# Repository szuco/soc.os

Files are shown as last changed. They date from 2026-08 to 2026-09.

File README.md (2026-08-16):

# KiCad SwitchStack

Dreistufiges ESP32-Steuerungsmodul für eine massive Schalter-Unterputzdose (61 mm tief).
Drei gestapelte Leiterplatten steuern zwei 24-V-Jalousiemotoren, lesen Sensorik aus und
kommunizieren primär über RS-485. **Bottom und Mid sind rund (Ø 52 mm) und sitzen in der
Dose; Top ist quadratisch (47 × 47 mm) und sitzt davor** — hinter der Busch-Jaeger
Zentralscheibe 6435-914, deren Drucktasten in den Ecken liegen.

## Zentrale Designregel

Das System ist konsequent in drei Stör- und Leistungsdomänen getrennt:

| Ebene | Projekt | Domäne |
|---|---|---|
| **TOP** | `hardware/top_ui` | UI und Sensorik |
| **MID** | `hardware/mid_logic` | Digitale Logik und Kommunikation |
| **BOTTOM** | `hardware/bottom_power_motor`  | 24-V-Leistung, Motoren, DC/DC |

Hochstrom bleibt **vollständig** auf dem Bottom-Board. Die Board-to-Board-Stackverbinder
transportieren ausschließlich Signale und Kleinleistung. Diese Trennung ist für Bauraum,
EMV, Messqualität und Wartbarkeit zentral.

## Eckdaten

- Versorgung: 24 V DC über zwei Adern
- 2 × Klappladenmotor 24 V DC ±10 %, 2 Adern, Umpolung — Laufstrom ≈ 0,3–1,0 A, Blockierstrom offen
- Herrnhuter Mini-Weihnachtsstern 6,0–6,5 V / 0,5 W / ≈ 80 mA, nur im 24-V-Normalbetrieb
- USB-C ausschließlich für Programmierung und Debug
- Positionserkennung ausschließlich über Stromverlauf und Timeout, keine Endschalter
- KiCad-Version: **10.0.5** (migriert von 9.0.7, siehe `docs/08-kicad-workflow.md`)

## Dokumentation

| Dokument | Inhalt |
|---|---|
| [`docs/00-system-overview.md`](docs/00-system-overview.md) | Gesamtsystem, Peripherie, Board-Aufteilung |
| [`docs/01-power-tree.md`](docs/01-power-tree.md) | Power-Tree, Strombilanz, USB-ORing, Schutz |
| [`docs/02-motor-control.md`](docs/02-motor-control.md) | H-Bridges, Strommessung, Überstromschutz, Software-Konzept |
| [`docs/03-stack-pinout.md`](docs/03-stack-pinout.md) | Stackverbinder, verbindliches Pinmapping |
| [`docs/04-mechanical.md`](docs/04-mechanical.md) | Outline, Bohrbild, Koordinaten, Tiefenbudget |
| [`docs/05-manufacturing.md`](docs/05-manufacturing.md) | Lagenaufbau, Kupfer, DRC, Fertigungsdaten |
| [`docs/06-open-decisions.md`](docs/06-open-decisions.md) | Offene Bauteil- und Auslegungsentscheidungen |
| [`docs/07-roadmap.md`](docs/07-roadmap.md) | Konkrete Arbeitsschritte in Reihenfolge |
| [`docs/08-kicad-workflow.md`](docs/08-kicad-workflow.md) | KiCad-Konventionen, Bedienhinweise, Repo-Regeln |
| [`docs/09-display-and-mcu.md`](docs/09-display-and-mcu.md) | Displaywahl, MCU, GPIO-Budget, ESPHome-Grenzen |
| [`docs/10-firmware-strategy.md`](docs/10-firmware-strategy.md) | Firmware-Schichten, ESPHome-Unabhängigkeit, Modbus-Pfad |
| [`docs/11-motor-data.md`](docs/11-motor-data.md) | Motordatenblatt, Leistungsanalyse, **Messprotokoll M1–M7** |
| [`docs/12-legacy-socos.md`](docs/12-legacy-socos.md) | Vorgängerprojekt SoC OS: übernommene Anforderungen, verlorene Funktionen, Restriktionen |
| [`docs/13-funktionsstatus.md`](docs/13-funktionsstatus.md) | **Was steht, was fehlt** — Hardware, Firmware und Mechanik nebeneinander |
| [`hardware/bom/README.md`](hardware/bom/README.md) | Beschaffungsliste, Fertigerempfehlung, Bestellweg |

## Repository-Struktur

```
hardware/
  bottom_power_motor/   KiCad BOTTOM (24 V, Motor, DC/DC)
  mid_logic/            KiCad MID (ESP32-S3, RS-485, Expander, PhotoMOS, Piezo)
  top_ui/               KiCad TOP (USB-C, Display 1,69", 4 Ecktaster, SHT4x, ToF, Stern)
  lib/                  Gemeinsame Symbol-/Footprint-/3D-Bibliotheken
  bom/                  Beschaffung und Fertigerempfehlung
  fab/                  Erzeugte Fertigungsdaten und der Nutzen (Build-Ergebnis)
mechanical/             Adapter zur BJ-Zentralscheibe: build123d-Modell, STEP/STL
tools/                  Generatoren (Mechanik, Schaltpläne, Layouts, Routing, Fertigung)
firmware/
  esphome/              ESPHome-Konfiguration für Home Assistant
docs/                   Projektübergreifende Spezifikationen
```

Ein Verzeichnis `archive/` mit dem Altbestand der Vorgängerprojekte gab es bis zum
15.08.2026. Es ist ausgewertet und entfernt; das Ergebnis steht in
[`docs/12-legacy-socos.md`](docs/12-legacy-socos.md), die Dateien selbst liegen nur
noch in der Git-Historie.

## Erzeugen

Die mechanischen Teile sind **generiert, nicht handgezeichnet** — damit können die drei
Boards nicht auseinanderlaufen:

```bash
python3 tools/gen_boards.py          # 3 × .kicad_pcb: Outline, Bohrbild, Keepout
python3 tools/gen_bottom_sch.py      # Bottom-Schaltplan + BOM, mit Netzlistenprüfung
python3 tools/gen_mid_sch.py         # Mid-Schaltplan (ESP32, RS-485, Expander)
python3 tools/gen_top_sch.py         # Top-Schaltplan (USB-C, Taster, Sensorik)
python3 tools/gen_layouts.py         # 3 Layouts: Platzierung, Netze, Zonen, DRC
python3 tools/route_boards.py        # Freerouting-Pipeline (Container, s. docs/05)
python3 tools/gen_fab.py [board]     # Gerber/Drill/Pos + BOMs, nur nach DRC-Gate
python3 tools/gen_panel.py           # Fertigungsnutzen aus den drei Quellprojekten
python3 mechanical/adapter.py        # Adapter für die BJ-Zentralscheibe, mit Selbsttest
```

Jedes dieser Skripte prüft sein Ergebnis und meldet Abweichungen. `gen_boards.py`,
`gen_layouts.py`, `gen_fab.py` und `gen_panel.py` brauchen die `pcbnew`-Python-API aus
einer KiCad-Installation, `adapter.py` braucht `build123d` (`pip install build123d`),
`route_boards.py` einen Container (siehe `docs/05`).

Dazu zwei Werkzeuge ohne Hardware: `python3 tools/display_mock.py` zeichnet den
Displayinhalt als PNG, und `esphome compile firmware/esphome/switchstack.yaml`
übersetzt die Firmware vollständig.

Auch der Bottom-Schaltplan wird erzeugt: Die Konnektivität steht als Quelltext, und
nach dem Schreiben liest `kicad-cli` die Netzliste zurück und vergleicht sie gegen
genau diese Vorgabe. Das Ergebnis ist zweckmäßig gezeichnet, aber nachweislich
korrekt — und in KiCad frei umarrangierbar.

## Status

Vollständige Gegenüberstellung von umgesetzten und fehlenden Funktionen:
[`docs/13-funktionsstatus.md`](docs/13-funktionsstatus.md).

| Teil | Stand |
|---|---|
| Systemspezifikation, Power-Tree, Pinmapping | dokumentiert |
| Mechanik der drei Boards | erzeugt und verifiziert |
| Front | **Serienteil**: BJ-Zentralscheibe 6435-914 im Rahmen 1721-914. Der **Adapter** dazwischen ist erzeugt und selbstgeprüft (`mechanical/adapter.py`) |
| Schaltpläne aller drei Boards + Stücklisten | **erzeugt und netzlistengeprüft** — Schaltungsreview gegen Datenblätter steht aus |
| Layouts aller drei Boards: Platzierung + Zonen | **erzeugt, DRC ohne Platzierungsfehler** |
| **Routing BOTTOM** | 985 Segmente, 102 Vias, **43 Verbindungen offen** — Rest Handarbeit (docs/05 verlangt das für Leistungspfade ohnehin) |
| **Routing MID** | **746 Segmente, 104 Vias** (16.08.2026, Container). Offen: 18 Signalverbindungen und **ein Kurzschluss** `HOOD_B`/`RELAY_LED` an einer Stelle — Handarbeit, s. docs/05 |
| **Routing TOP** | **197 Segmente, 12 Vias** (16.08.2026, Container). Offen: 14 Signale, darunter **alle vier Tastenleitungen und drei USB-Netze**; dazu **eine neue Kollision** einer Leiterbahn mit dem Befestigungsloch der USB-Buchse |
| Fertigungsnutzen (3 Platinen in einer Boarddatei) | **erzeugt:** `hardware/fab/panel/` — 173,4 × 64,4 mm, zwei Kreise + ein Quadrat |
| Fertigungsdaten | **keine** — `python3 tools/gen_fab.py` nach dem Routing, mit DRC-Gate |
| ESPHome-Firmware | **übersetzt** (`esphome compile`, 2026.7.4 / IDF 5.5.5): RAM 35 %, Flash 56 %. Alle Lambdas geprüft. Motoren fahren **auf Zeit** |
| Lasterkennung, ToF-Distanz, RS-485-Protokoll | **fehlen** — die ersten beiden brauchen eine eigene C++-Komponente, s. docs/13 |
| Gefertigt oder gemessen | **nichts** |

Nächste Schritte: [`docs/07-roadmap.md`](docs/07-roadmap.md).
Der kritische Pfad ist die Messung des Blockierstroms — Messprotokoll in
[`docs/11-motor-data.md`](docs/11-motor-data.md), Abschnitt 4. Ohne sie bleiben
Sicherungen, Trip-Schwellen, Treiberauswahl und Steckverbinder provisorisch.

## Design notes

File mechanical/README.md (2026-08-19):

# Adapter für die Busch-Jaeger Zentralscheibe

Die Sichtfläche dieses Geräts wird **nicht** mehr selbst gestaltet. Sie ist ein
Serienteil:

| Teil | Bestellnummer |
|---|---|
| Zentralscheibe 6435-914, Aufdruck „Pfeile und OK", Busch-balance SI | 2CKA006430A0402 |
| Abdeckrahmen 1721-914, 1-fach, Busch-balance SI | 2CKA001725A1555 |

Erzeugt wird nur noch das **Bindeglied** dazwischen: ein 3D-gedruckter Adapter,
der **alle drei Aufgaben in einem Teil** übernimmt:

1. **Tragring** — wird mit zwei Schrauben auf 60 mm in die Dose geschraubt
2. **Rahmenhalt** — der Abdeckrahmen klemmt auf seinen 70,0 mm
3. **Träger** — Leiterplatte in der Tasche, Zentralscheibe rastet auf

Montagereihenfolge: Adapter anschrauben, Rahmen aufsetzen, Zentralscheibe
aufstecken. Die Scheibe ist das einzige Teil, das ohne Werkzeug abgeht — und
darunter liegt der USB-Anschluss.

> Ein fertiger **Blech-Tragring** war zwischenzeitlich im Gespräch, ist aber
> verworfen: Er baut zusätzlich auf, und seine Krallen werden nicht gebraucht.
> Er bleibt der Rückfallweg, falls die gedruckten Schraubaugen nicht halten
> (Punkt 51).

> Die frühere Frontplatte mit vier **Sicheltasten** ist am 16.08.2026 gelöscht
> worden. Sie war eine vollständige Eigenentwicklung samt Tastenkappen und
> Druckstößeln; mit dem Wechsel auf die Zentralscheibe hat sie ihren Gegenstand
> verloren. Modell und Exporte liegen in der Git-Historie.

## Dateien

| Datei | Zweck |
|---|---|
| `adapter.py` | Parametrisches Modell (build123d). **Referenz** — erzeugt die Exporte und prüft sich selbst |
| `export/adapter.step/.stl` | Adapter |

```bash
pip install build123d
python3 mechanical/adapter.py
```

Alle Parameter stehen im `PARAMS`-Block. Nach jeder Änderung neu laufen lassen —
der Selbsttest prüft die rechnerischen Zwangsbedingungen (Rastmaß, Wandstärke,
Tasterausdehnung, Auflagebreite) **und** nimmt Materialproben an Schnapprand,
Rastraum, Platinenauflage, Taschenwand und Schraubschlitzen.

## Die Tiefenkette

Sie bestimmt alles Übrige. z zählt von der Sichtfläche der Scheibe nach hinten:

| von … bis | was |
|---|---|
| 0,0 … 1,0 | Zentralscheibe, Sichtfläche |
| 1,0 … 2,5 | Druckkreuz auf ihrer Rückseite |
| 2,5 … 4,5 | SMD-Taster über der Leiterplatte |
| 4,5 … 5,5 | Top-Leiterplatte |
| 7,5 | Rastebene und hinterer Rand der Scheibe |

**Die Rastebene liegt hinter der Leiterplatte.** Der Schnapprand steht deshalb
hinter ihr und trägt sie zugleich — Rastglied und Auflage in einem.

## Geometrie

| Merkmal | Wert |
|---|---|
| Tragring-Flansch | 70,0 × 70,0 × 2,5 mm — darauf klemmen die Doppelstege des Rahmens |
| Geräteschrauben | Langlöcher 3,9 mm auf **60 mm** Achsabstand (DIN 49073) |
| Schnapprand | außen 49,8 mm; die Scheibe rastet auf lichte 50,0 |
| Rastraum | springt 1,5 mm zurück, 1,3 mm tief — dort sitzen die vier Nasen |
| Platinentasche | 47,4 mm für das Top-Board 47,0 × 47,0 |
| Auflage | 2,0 mm ringsum |
| Zentrale Durchführung | 43 × 43 mm für die beiden Stackverbinder |
| Gesamthöhe | 10,0 mm |

**Das Maß 47,0 ist keine gewählte Zahl**, sondern liegt zwischen zwei harten
Grenzen: Nach oben begrenzt der Schnapprand (49,8 außen, 1,4 mm Wand), nach
unten die Taster — sie stehen auf (±18 · ±20) und reichen mit Footprint bis
22,2, mit Randabstand also mindestens 45,4.

## Was noch fehlt

- **Bauhöhe des realen Displaymoduls** (Punkt 15c). Zwischen Platinenoberfläche
  und Innenseite der Scheibe stehen 4,5 mm; ein typisches 1,69″-Modul baut
  2,5–3,0 mm. Ob es die Scheibe berührt oder eine Unterlage braucht,
  entscheidet das reale Teil.
- **Lichtkanal für den ToF.** Die vier Durchbrüche der Scheibe liegen bei
  (±9 · ±19) und damit innerhalb der zentralen Durchführung — der Adapter steht
  ihnen nicht im Weg. Ob der Sensor einen eigenen Kanal gegen Streulicht
  braucht, zeigt der reale Aufbau.
- **Sicherung der Platine gegen Herausfallen.** Heute hält sie die Scheibe, die
  über die Taster auf sie drückt. Ob das reicht, zeigt der erste Druck.
- **Nullspalt zwischen Druckkreuz und Taster** (Punkt 62). Kreuzunterkante und
  Tasteroberkante liegen beide auf 2,5 — die Tiefenkette hat kein nachgiebiges
  Glied, jede Toleranz landet direkt auf dem Schaltweg.
- **Wer hält Mid und Bottom** (Punkt 61). Die Befestigungsbohrungen auf
  r = 21,5 haben im Adapter kein Gegenstück; der Stapel hängt an den beiden
  Stackverbindern.

Herleitung und Messprotokoll: [`../docs/04-mechanical.md`](../docs/04-mechanical.md),
Abschnitte 1b bis 1e.

**Einbaureihenfolge, Kraftfluss und Toleranzen** — wer wen hält, was wann
gefügt wird und wo die Reihenfolge zwingend ist:
[`../docs/18-montage-und-kraefte.md`](../docs/18-montage-und-kraefte.md).

**Maßstäbliche Schnitte durch die Front** (zwei Schnittebenen, Draufsicht,
eingebaute Tiefenlage): [`../docs/renders/front-explosion.png`](../docs/renders/front-explosion.png),
erzeugt von [`../tools/gen_explosion.py`](../tools/gen_explosion.py). Das
Werkzeug liest die Maße mit `ast` aus `adapter.py`, `stack.py` und den
Layoutkonstanten — es braucht weder KiCad noch build123d und lädt die 57 MB
große Baugruppen-STEP **nicht**. Nach jeder Parameteränderung neu laufen
lassen; `tools/render_all.py` stößt es ohnehin mit an.

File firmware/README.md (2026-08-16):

# Firmware

ESP32-Firmware für KiCad SwitchStack. Dieses Dokument hält das festgelegte Konzept
fest, damit es die Hardwareauslegung mitbestimmen kann.

## Was heute läuft — und was nicht

`esphome/switchstack.yaml` ist mit `esphome config` validiert und deckt die
Grundfunktionen ab: Display mit Init-Sequenz, Backlight mit Präsenz-Dunkeltastung,
SHT4x, Expander, Hard-Trip-Meldung und -Reset, Verschlusskontakte, Stern,
Haubenkontakt, zwei Cover und vier Tasten.

**Die vier größten Lücken**, jede mit einem Grund:

| Fehlt | Warum |
|---|---|
| **Lasterkennung / Stall** | Braucht PWM-synchrones ADC-Sampling; ESPHomes Polling-Modell kann das nicht. Die Cover fahren deshalb **auf Zeit**. |
| **ToF-Distanz, ROI, Blendung** | ESPHome hat nur `vl53l0x` nativ; heute wird nur der Interrupt-Pin gelesen („da / nicht da"). |
| ~~Bedienmenü~~ | **erledigt** — `graphical_display_menu`, siehe unten |
| **RS-485-Protokoll** | UART ist konfiguriert, aber ungenutzt; `RS485_DIR` unbelegt. Das ist der *primäre* Kommunikationsweg. |

### Anzeige und Menü

**Der Startbildschirm zeigt die Messwerte**, gezeichnet im `lambda` des
Displays — also in C++, das bei jedem Refresh läuft: Raumtemperatur groß,
Feuchte darunter, dann je Fenster Verschluss- und Sabotagezustand, die
Motorströme (nur wenn sie nennenswert sind), und in der Fußzeile Präsenz und
Stern. Alles frei gestaltbar; ESPHome bietet `printf`, Linien, Rechtecke,
Kreise, Bilder und beliebig viele Schriften.

**Das Menü bringt ESPHome mit.** `graphical_display_menu` kann Untermenüs,
Zahlenwerte, Schalter und Kommandos und wird über `display_menu.up/down/enter/
left` bedient — genau die vier Bedienrichtungen der Zentralscheibe. Damit ist
Punkt 37 ohne eigene Zustandsmaschine erledigt.

Jede Taste hat zwei Bedeutungen:

| Taste | im Menü | sonst |
|---|---|---|
| ↑ | nach oben | beide Jalousien auf |
| ↓ | nach unten | beide Jalousien zu |
| OK | auswählen | **Menü öffnen** |
| ▷ | eine Ebene zurück | alles anhalten |

Im Menü stehen unter anderem die **Fahrzeiten** — sie lassen sich also am
Fenster einstellen, ohne Home Assistant und ohne Flash.

Ein Detail, das leicht übersehen wird: Schriften brauchen ein `glyphs`-Feld,
sonst fehlen Umlaute und das Gradzeichen. ESPHome bettet nur die aufgezählten
Zeichen ein.

### Das Display vorher ansehen

`python3 tools/display_mock.py` zeichnet den Bildschirminhalt in Originalgröße
(280 × 240) als PNG — in drei Zuständen (Ruhe, Fahrt, Alarm) plus Menü, mit
einer Markierung dort, wo die Zentralscheibe oben und unten je gut vier Pixel
verdeckt.

**Das ist kein Emulator.** Es führt die Firmware nicht aus, sondern zeichnet
nach, was das Lambda zeichnet. Der Nutzen ist die Bildaufteilung: Passt der Text
in die Zeilen, kollidiert nichts, ist die große Zahl groß genug? Sonst ließe
sich das erst nach Kompilieren, Flashen und Blende-Abnehmen beurteilen.

Der Preis: Wer die Aufteilung ändert, ändert **beides** — das Lambda und den
Mock. Die Alternative wäre, es gar nicht vorher zu sehen.

### Einstellbar statt einkompiliert

Seit dem 16.08.2026 stehen die Werte, die an der Anlage nachgezogen werden
müssen, als `number`-Entitäten in Home Assistant — sie überleben einen Neustart
und brauchen keinen neuen Flash:

| Entität | Bedeutung |
|---|---|
| Fahrzeit 1/2 Auf und Zu | je Kanal **und Richtung** getrennt, 5–60 s |
| Sanftauslauf ab | ab wieviel Prozent der Fahrzeit gerampt wird |
| Sanftauslauf PWM | auf welchen Wert |
| Stromskalierung | A/V für die ADC-Sensoren, rechnerisch 20 (= 1/(1 mΩ × 50)) |

Möglich wird das, weil die Jalousien nicht mehr als `time_based`-Cover laufen —
deren Dauer steht zur Compilezeit fest — sondern als `template`-Cover mit
Fahrskripten, deren Verzögerungen Lambdas sind.

**Das ersetzt die Lasterkennung nicht.** Der Sanftauslauf läuft hier auf Zeit;
ihn am Stromverlauf festzumachen kann erst die C++-Komponente.

> **Vollständig übersetzt (ESPHome 2026.7.4, ESP-IDF 5.5.5): erfolgreich.**
> Nicht nur `esphome config`, sondern `esphome compile` — der echte Compiler
> über den erzeugten C++-Code. Damit sind auch **alle Lambdas geprüft**:
> Displayzeichnung, Menü-Abfragen, die Zeitberechnungen in den Fahrskripten und
> die Tastenpaare.
>
> | | |
> |---|---|
> | RAM | 35,1 % — 120 kB von 342 kB |
> | Flash | 55,6 % — 1 020 kB von 1 835 kB (ein OTA-Slot) |
>
> Der Weg dahin fand zwei echte Fehler: eine als Ganzes gelambdate
> `output.set_level`-Aktion (der Wert gehört an `level:`) und `format`-Strings
> der Menü-Zahlen mit Einheit, die genau eine Konversion enthalten dürfen.
>
> Was **nicht** geprüft ist, bleibt die Laufzeit: die Offsets des
> 240×280-Panels (0/20) und ob die Zentralscheibe die Taster sauber trifft.
>
> Eine Falle auf diesem Rechner, unabhängig vom Projekt: `ccache` aus Homebrew
> ist gegen `libfmt.11` gelinkt, installiert ist `libfmt.12` — jeder
> Compileraufruf stirbt sofort. Umgehung: `IDF_CCACHE_ENABLE=0`.

Die ersten beiden fallen in **dieselbe** External Component. Vollständige
Gegenüberstellung: [`../docs/13-funktionsstatus.md`](../docs/13-funktionsstatus.md).

## Architekturregel (verbindlich)

Aus [`../docs/10-firmware-strategy.md`](../docs/10-firmware-strategy.md):
**Gerätelogik frameworkfrei, Glue dünn.** Motorregelung, Lasterkennung,
Trip-Handling und Display-Zustandsmaschine sind reine C++-Klassen ohne
`esphome::`-Abhängigkeit. ESPHome (und eine spätere Modbus-Registerkarte)
docken über dünne Adapter an. ESPHome ist Integrationsrahmen — es hat kein
Vetorecht über die Hardwareauswahl; fehlende Treiber werden als External
Component um die offiziellen Espressif-Treiber (`esp_lcd_*`) gewickelt.

## Motor-Softwarekonzept

### Harte Grenzen

| Regel | Wert |
|---|---|
| Maximale Laufzeit einer Bewegung | **30 s** (Fahrzeit real 18 s + Reserve) |
| Blanking des Anlaufstroms in der Lastanalyse | **≈ 600 ms** (Startwert) |
| Mechanische Stopzeit vor Richtungswechsel | ≥ 300 ms (Startwert) |
| Software-Soft-Limit | ≈ 9 A (vorläufig) |
| Beginn des Sanftauslaufs | ab **≈ 80 %** der erwarteten Fahrzeit (Startwert) |
| PWM im Sanftauslauf | von 100 % auf ≈ **40 %** rampen (Startwert) |

### Endlagen: Zeitkonstante, Strom — und Sanftauslauf

**Die Endlage wird ausschließlich aus der Fahrzeit und dem Stromverlauf
bestimmt.** Es gibt keine Endschalter, und die Reed-Kontakte gehören nicht dazu
(Abschnitt unten).

Daraus folgt eine dritte Anforderung, die über reines Erkennen hinausgeht:
**Die Läden müssen langsamer werden, wenn sie sich der vermuteten Endlage
nähern.** Der Grund ist mechanisch — bei voller Drehzahl in den Anschlag zu
fahren belastet Getriebe, Beschlag und Mauerwerk, und der Stromanstieg beim
Auflaufen ist bei voller Fahrt so steil, dass die Abschaltung erst nach dem
Schlag kommt. Mit reduzierter Drehzahl wird der Anstieg flacher und früher
auswertbar, und der Anschlag wird weich.

Ablauf einer Fahrt:

1. **Anlauf**, die ersten ≈ 600 ms in der Lastanalyse ausgeblendet.
2. **Fahrt** mit voller PWM, Lastüberwachung nach dem Verfahren unten.
3. **Sanftauslauf** ab ≈ 80 % der erwarteten Fahrzeit: PWM linear auf ≈ 40 %
   rampen. Die Schwellwerte der Lastanalyse müssen dabei mitgeführt werden —
   bei halber PWM ist auch der Normalstrom kleiner.
4. **Abschaltung** beim Stromanstieg des Anschlags, spätestens nach 30 s.

Die erwartete Fahrzeit ist keine Konstante für die Ewigkeit: Sie ist je Laden
und Richtung zu führen und nach jeder sauber beendeten Fahrt nachzuziehen —
sonst wandert der Umschaltpunkt mit Temperatur und Verschleiß aus dem Fenster.
Startwert ist die Datenblatt-Fahrzeit von 18 s.

### Lasterkennung

Positionsfeedback erfolgt ausschließlich über **Stromverlauf und Timeout**. Es gibt
keine Endschalter.

Verfahren:

1. Beim Start des Motors die ersten ≈ 600 ms in der Lastanalyse ausblenden, damit der
   Anlaufstrom nicht als Blockade gewertet wird.
2. Danach einen **schnellen Strommittelwert** gegen eine **langsamere Baseline**
   vergleichen. Bewertet wird der **relative** Anstieg, nicht der Absolutwert — dadurch
   ist das Verfahren unempfindlich gegen Exemplarstreuung, Temperatur und
   Versorgungstoleranz.
3. Bei erkanntem Lastanstieg zunächst die PWM reduzieren.
4. Bei weiterem Anstieg bzw. Stall abschalten.
5. Nach 30 s in jedem Fall abschalten.

Der **Hardware-Hard-Trip bleibt davon vollständig unabhängig** und wirkt auch bei
abgestürzter oder nicht geladener Firmware. Die Firmware darf sich niemals darauf
verlassen, alleiniger Schutz zu sein — und umgekehrt darf der Hardware-Trip nicht als
regulärer Betriebszustand eingeplant werden.

### Abhängigkeiten zur Hardware

Diese Punkte müssen vor der Implementierung geklärt sein:

- **Sense-Topologie.** Bei Low-Side-Shunt muss das ADC-Sampling PWM-synchron erfolgen,
  sonst misst die Lasterkennung bei reduzierter PWM systematisch zu wenig — genau im
  Betriebsfall aus Schritt 3. Siehe [`../docs/02-motor-control.md`](../docs/02-motor-control.md).
- **ADC-Quelle.** Interner ESP32-ADC oder externer ADC. Der interne ADC ist nichtlinear
  und für relative Auswertung grenzwertig brauchbar, für PWM-synchrones Sampling aber
  unbequem.
- **Reale Anlaufströme.** Bestimmen das Blanking-Fenster und das Soft-Limit.
- **Gleichzeitiger Motorbetrieb.** Falls ein Interlock entschieden wird, ist er in der
  Firmware als harte, nicht umgehbare Regel zu implementieren — die
  Steckverbinder- und Sicherungsauslegung hängt dann davon ab. Siehe
  [`../docs/01-power-tree.md`](../docs/01-power-tree.md).

## Verhaltensregeln aus dem Vorgängerprojekt

Vier Festlegungen stammen aus der SoC-OS-Firmware und gelten sprachunabhängig
weiter. Sie sind **als Anforderung übernommen, nicht als Code** — die Altfirmware
war ein Laboraufbau, in dem Watchdog, Buzzer, BIST und Menü auskommentiert waren.
Herleitung und ehrliche Einordnung: [`../docs/12-legacy-socos.md`](../docs/12-legacy-socos.md)
Abschnitt 4.

| Regel | Inhalt |
|---|---|
| **BIST beim Hochlauf** | Vor dem Start der Regeltasks ein definierter Selbsttest mit hörbarer und sichtbarer Quittung (Piezo-Ton, Displaybild). In einer zugeschraubten Unterputzdose ist das der einzige Funktionsnachweis der Peripherie ohne Bus. |
| **Heartbeat** | Ein Lebenszeichen im festen Takt (Original: LED alle 500 ms), unabhängig von Bus und Display. Trennt „Firmware hängt" von „Kommunikation gestört" — zwei Fehlerbilder, die sonst identisch aussehen. |
| **Tastenbelegung** | Vier Tasten. **Achtung, die Hardware liefert sie nicht direkt:** Die Zentralscheibe trägt die Symbole ↑ ▷ ↓ OK auf den Achsen, überträgt den Druck aber auf vier Taster an den **Ecken**. Jede Richtung ist ein *Paar*: ↑ = oben links + oben rechts, ↓ = unten links + unten rechts, ▷ = links oben + links unten, OK = rechts oben + rechts unten. Die Zuordnung Paar → Funktion gehört in die Eingabeschicht, bevor das Menü sie sieht. Ursprüngliche Belegung aus dem Vorgängerprojekt: **OK / Hoch / Runter / Home**. `Home` führt aus *jeder* Menütiefe direkt zur Hauptansicht zurück; das Original hatte dafür zusätzlich einen eigenen RESET-Taster, den diese Hardware nicht mehr hat. Entprellung 50 ms, flankengetriggert. Offen als Punkt 37 in [`../docs/06-open-decisions.md`](../docs/06-open-decisions.md). |
| **Eine Task je Funktionsblock** | Kooperatives Modell mit eigener Periode je Block (Motor, Sensorik, UI, Kontakte) statt einer Sammelschleife. Deckt sich mit der frameworkfreien Kernregel oben. |

### Die Reed-Kontakte sichern das Fenster, nicht den Laden

**Festgelegt am 15.08.2026, und zwar gegen die Herleitung aus dem Vorgängerprojekt.**
`REED1_IN`/`REED2_IN` überwachen **das Fenster** — geschlossen oder offen. Mit der
Endlage der Klappläden haben sie **nichts** zu tun, und die Motorlogik darf sie
dafür auch nicht heranziehen.

Das korrigiert eine frühere Fassung dieses Abschnitts. Sie schloss aus den
Blattnamen des Vorgängerentwurfs („Verschlussüberwachung Links/Rechts") auf eine
Endlagenmeldung und nannte die Kontakte den „einzigen absoluten Positionsbezug im
System". Das war eine Übernahme aus alten Unterlagen, keine Festlegung für dieses
Gerät. Der Einordnung in [`../docs/12-legacy-socos.md`](../docs/12-legacy-socos.md)
ist damit die Grundlage entzogen.

Praktische Folge: **Es gibt keinerlei absolute Positionsrückmeldung der Läden.**
Die Endlagenbestimmung ruht vollständig auf den zwei Verfahren im nächsten
Abschnitt, und der Sicherheitsfall „Laden fährt gegen ein Hindernis" wird
ausschließlich vom Strom erkannt.

## Weitere Funktionsbereiche

Noch nicht spezifiziert, aus der Hardware abgeleitet:

- RS-485 als primäres Protokoll — Protokollwahl offen
- Präsenzauswertung über den ToF-Sensor VL53L1X (ersetzt den früheren Radar)
- Runddisplay-Anzeige und Bedienung über vier Taster
- Temperatur- und Feuchtemessung — Zuordnung Innen-/Außenmessung offen, Punkt 35
- Alarmierung über Piezo
- Ansteuerung des Stern-Ausgangs und des Haubenkontakts (PhotoMOS)
- Sabotagekontakte, falls Punkt 34 dafür entschieden wird
- WLAN sekundär

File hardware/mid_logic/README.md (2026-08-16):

# MID – Logic

KiCad-Projekt `mid_logic`. Logik- und Kommunikationsebene des Stacks.

## Umfang

Bestückt sind 37 Bauteile, 57 Netze (`bom_mid.csv`):

- **ESP32-S3-WROOM-1-N16R8** als zentrale Steuerung, RESET- und BOOT-Taster
- **MAX3485** als **primäre** Kommunikation: `RS485_DIR` schaltet DE und /RE
  gemeinsam, Fail-Safe-Bias 2 × 560 R, Terminierung 120 R als **DNP** (nur am
  Busende bestücken), JST-XH 3-polig
- **PCF8574** (0x20) als GPIO-Expander für die langsamen Signale: `HW_TRIP1/2`,
  `TRIP_RST`, `STAR_EN`, `PRESENCE_INT`, `RELAY_CTL`, `REED1/2` — **P0–P7 sind
  damit restlos belegt** (relevant für Punkt 34)
- **Piezo passiv** mit Treiberstufe — ein aktiver Summer kann keine Melodien
- **PhotoMOS AQY282GS** als potentialfreier Meldekontakt zur Dunstabzugshaube,
  **ausschließlich SELV**, mit 33-V-Klemmdiode
- **Feldstecker JST-SH 6-polig** für zwei Verschlusskontakte und die Haube,
  je Reed 10k Pull-up, 1k Serie und 5V6-ESD-Diode
- Stackverbinder `J_STK_A` und `J_STK_B` nach unten und nach oben

Ein externer ADC ist **nicht** bestückt — die Strommessung hängt am internen ADC
des S3 (offener Punkt 18). Die frühere Radar-Schnittstelle ist entfallen; der
Präsenzsensor sitzt als VL53L1X auf dem Top-Board.

## Kernregeln

- **Antennen-Keepout:** ESP32-Antennenbereich kupfer- und bauteilfrei auf **allen** Lagen,
  Antenne möglichst zur Front orientiert. WLAN ist sekundär — in einer massiven
  Unterputzdose ist die Performance realistisch schwach, deshalb RS-485 als primäre
  Kommunikation.
- Keine Motorströme, keine USB-Datenleitungen auf diesem Board.
- Durchgehende GND-Referenzlage, 4 Lagen empfohlen.

## Mechanik

- Ø 52,0 mm, 1,0 mm Dicke
- Bohrbild und Stackverbinder-Positionen **deckungsgleich** mit BOTTOM und TOP
- Abstand nach unten und nach oben je **10 mm** — gleicher Verbinder, gleicher Abstand

Exakte Koordinaten: [`../../docs/04-mechanical.md`](../../docs/04-mechanical.md)

## Referenzdokumente

- [`docs/03-stack-pinout.md`](../../docs/03-stack-pinout.md) – Pinmapping beider Verbinder
- [`docs/00-system-overview.md`](../../docs/00-system-overview.md) – Peripherieübersicht
- [`docs/06-open-decisions.md`](../../docs/06-open-decisions.md) – ESP32-Modul, Transceiver, ADC, Feldstecker
- [`docs/13-funktionsstatus.md`](../../docs/13-funktionsstatus.md) – Gesamtstand

## Status

**Schaltplan erzeugt und netzlistengeprüft** (`tools/gen_mid_sch.py`, 37 Bauteile,
57 Netze, Netzlistenvergleich bestanden). Stückliste `bom_mid.csv` aus derselben
Quelle.

**Layout:** platziert, Zonen angelegt — **aber ohne eine einzige Leiterbahn.**
Es gab einmal einen vollständig gerouteten Stand (655 Segmente, 73 Vias); der
Umbau auf Reed-Kontakte und Haubenkontakt am 15.08.2026 hat das Layout neu
erzeugt und die Verdrahtung damit verworfen. Sie ist neu zu ziehen — Pipeline:
`tools/route_boards.py`, Massenacharbeit mit `tools/gnd_*.py`.

**Nicht geprüft:** Schaltungsreview gegen Datenblätter (MAX3485-Pinbelegung,
PhotoMOS-LED-Strom). Die Netzliste stimmt mit der Sollvorgabe überein — mehr sagt
sie nicht.

**Offen und layoutrelevant:** Punkt 29 (der Feldstecker sitzt 0,4 mm neben einem
Keepout) und Punkt 34 (Sabotagekontakte hätten hier keinen Expanderpin mehr).

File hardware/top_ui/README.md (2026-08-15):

# TOP – Front / UI

KiCad-Projekt `top_ui`. Bedien- und Sensorikebene des Stacks, zur Front orientiert.

## Umfang

Bestückt sind 29 Bauteile, 53 Netze (`bom_top.csv`):

- **USB-C-Buchse, stehend** (G-Switch GT-USB-7051x, vertikal SMT) — zeigt nach
  vorn und liegt unter der Zentralscheibe, mit **USBLC6-2SC6** als ESD-Schutz
  und 2 × 5k1 Rd
- **Runddisplay ST77916**, 1,46", 360 × 360, QSPI — über eine Steckerleiste;
  der Footprint ist ein **Platzhalter**, bis das reale Modul mit seinem FPC
  vermessen ist
- **Vier SMD-Taster** auf (±18 · ±20), exakt unter den Druckkreuzen der
  Zentralscheibe. Einzeln bedeuten sie nichts — jede Bedienrichtung ist ein
  Paar benachbarter Ecken, aufgelöst in der Firmware
- **SHT40-AD1B** (0x44) für Temperatur und Feuchte, thermisch über Schlitze
  entkoppelt
- **VL53L1X** als Präsenz- und Durchstiegssensor hinter dem **oberen** Steg
  (12 Uhr), XSHUT über 10k dauerhaft aktiv
- **Stern-Ausgang** über P-FET-High-Side und 0,2-A-PTC auf eine
  2,5-mm-Klinkenbuchse im **unteren** Steg (6 Uhr, Footprint noch Platzhalter,
  Punkt 30)
- `J7` als **unbestückte Reserve-UART** für ein späteres Satellitenmodul
- Stackverbinder `J_STK_A` und `J_STK_B` nach unten

Ein USB-UART-Baustein entfällt — der ESP32-S3 hat nativen USB (Punkt 24).

## Kernregeln

- **USB `D+`/`D−` laufen durch den Stack** (`J_STK_A` 34/36, benachbart, PGND
  daneben). Das ist die Regeländerung v0.3 in
  [`docs/03-stack-pinout.md`](../../docs/03-stack-pinout.md): Mit dem nativen USB
  des ESP32-S3 auf dem **Mid**-Board gibt es keine Alternative, und Full-Speed-USB
  über zwei benachbarte Kontakte ist unkritisch.
- ESD-Schutz unmittelbar an der USB-C-Buchse, `D+`/`D−` kurz führen.
- USB-C bleibt **Device/UFP**: `CC1` und `CC2` jeweils einzeln mit 5,1 kΩ Rd nach GND.
- Der Stern-Ausgang wird aus `6V2_STAR` über den Stack versorgt und leuchtet damit nur im
  24-V-Normalbetrieb — **nicht** aus USB-VBUS speisen.

## Mechanik

- **47 × 47 mm mit R 4**, 1,0 mm Dicke — als einziges Board nicht rund
- Bohrbild und Stackverbinder-Positionen **deckungsgleich** mit BOTTOM und MID
- Das Board ist **quadratisch, 47 × 47 mm mit R 4** — als einziges der drei.
  Es sitzt vor der Dose im Adapter, weil die Druckkreuze der Zentralscheibe auf
  r = 26,9 liegen und ein Kreis dort nicht hinreicht. Geometrie und Tiefenkette:
  [`mechanical/adapter.py`](../../mechanical/adapter.py)
- Frontorientierung: mathematisch +Y = „oben“, identisch auf allen drei Boards

Exakte Koordinaten: [`../../docs/04-mechanical.md`](../../docs/04-mechanical.md)

## Referenzdokumente

- [`docs/01-power-tree.md`](../../docs/01-power-tree.md) – USB-ORing, Stern-Versorgung
- [`docs/03-stack-pinout.md`](../../docs/03-stack-pinout.md) – Pinmapping
- [`docs/04-mechanical.md`](../../docs/04-mechanical.md) – Stern-Ausgang, Tiefenbudget
- [`docs/09-display-and-mcu.md`](../../docs/09-display-and-mcu.md) – Displaywahl, MCU, ToF
- [`docs/13-funktionsstatus.md`](../../docs/13-funktionsstatus.md) – Gesamtstand

## Status

Schaltplan erzeugt und netzlistengeprüft (`tools/gen_top_sch.py`, 29 Bauteile,
53 Netze).

**Layout: platziert, ohne Leiterbahnen.** Stand vom 15.08.2026, an diesem Tag
zweimal neu erzeugt:

1. **J1 stand um 180° verdreht** (Punkt 39) — die Stecköffnung zeigte zur
   Platinenmitte, die Lötpads standen über die Kante, sechs Bohrungen schnitten
   die Ø-52-Kontur an. Korrigiert: das engste Pad liegt jetzt 3,2 mm innerhalb
   der Kontur, die Randabstandsverletzungen sind von 11 auf 1 gefallen.
2. **Klinke und ToF getauscht**: Die Klinkenbuchse sitzt jetzt im **unteren**
   Steg (6 Uhr, mittig), der ToF allein im **oberen** (12 Uhr). Die USB-C-Buchse
   musste dafür von 6 nach 12 Uhr weichen und liegt links neben dem ToF; der
   unbestückte Reserve-UART J7 ist nach innen gerückt.

Die verbliebene Randabstandsverletzung gehört dem **Platzhalter**-Footprint der
Klinkenbuchse: Der 3,5-mm-Typ ist 14,4 mm lang, sein Bund sitzt in der Mitte —
bei einem Lochabstand von r = 22,5 steht das hintere Ende 3,3 mm über die
Platinenkante. Das reale 2,5-mm-Teil muss deutlich kleiner sein, siehe Punkt 30.

**Zwei Footprints sind Platzhalter** und vor der Bestellung zu ersetzen:
die Displaystiftleiste (Punkt 15c) und die Klinkenbuchse (Punkt 30, 3,5 mm
vertikal statt der gewollten 2,5 mm). Beides sind reale Bauteilmaße, die am
gekauften Teil zu nehmen sind — nicht aus einem Katalog.

**Nicht geprüft:** Schaltungsreview gegen Datenblätter.

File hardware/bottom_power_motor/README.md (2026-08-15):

# BOTTOM – Power & Motor

KiCad-Projekt `bottom_power_motor`. Leistungsebene des Stacks.

## Umfang

- 24-V-Eingangsschutz: Sicherung, TVS, optionaler Verpolschutz
- Hochstrom-Steckverbinder nach unten, 6-polig
- Zwei Motor-H-Bridges für die Jalousiemotoren
- Strommessung getrennt pro Motor
- Hardwareseitige Überstromabschaltung, Comparator + Latch **pro Motor**
- DC/DC-Wandler: 24 → 5 V, 5 → 3,3 V, 24 → 6,2 V
- Mini-Relais (Zuordnung noch zu bestätigen)
- Stackverbinder `J_STK_A` und `J_STK_B` nach oben

## Kernregel

**Hochstrom bleibt vollständig auf diesem Board.** Motorströme werden niemals über die
Stackverbinder geführt.

## Mechanik

- Ø 52,0 mm, 1,0 mm Dicke
- Zwei Befestigungsbohrungen auf R = 21,5 mm bei 0° / 180° (Bohrbild v2, siehe docs/04)
- Bottom-Connector im Bereich −Y (unten), siehe Frontorientierung
- 2-oz-Kupfer prüfen

Exakte Koordinaten: [`../../docs/04-mechanical.md`](../../docs/04-mechanical.md)

## Referenzdokumente

- [`docs/01-power-tree.md`](../../docs/01-power-tree.md) – Power-Tree, Strombilanz, Schutz
- [`docs/02-motor-control.md`](../../docs/02-motor-control.md) – H-Bridges, Sense, Trip
- [`docs/03-stack-pinout.md`](../../docs/03-stack-pinout.md) – Stackverbinder
- [`docs/04-mechanical.md`](../../docs/04-mechanical.md) – Outline, Bohrbild, Tiefenbudget

## Dateien

| Datei | Stand |
|---|---|
| `bottom_power_motor.kicad_pcb` | Mechanik: Outline Ø 52 mm, Bohrbild, Dicke 1,0 mm |
| `bottom_power_motor.kicad_sch` | **Schaltplan, 103 Bauteile, 105 Netze** |
| `bom_bottom.csv` | Stückliste, aus derselben Quelle erzeugt |

Beides wird generiert, nicht von Hand gezeichnet:

```bash
python3 tools/gen_boards.py       # Mechanik
python3 tools/gen_bottom_sch.py   # Schaltplan + Stückliste + Netzlistenprüfung
```

## Status

**Schaltplan steht und ist netzlistengeprüft.** `tools/gen_bottom_sch.py` exportiert
nach dem Erzeugen die Netzliste mit `kicad-cli` und vergleicht sie gegen die im
Quelltext hinterlegte Soll-Konnektivität — 105 Netze, keine Abweichung, kein offener
Pin.

Enthalten: 24-V-Eingangsschutz (Sicherung, TVS, P-FET-Verpolschutz), 12-V-Gate-
Versorgung, drei DC/DC-Wandler, USB-ORing, Stern-Ausgang mit Polyfuse, zwei
vollständige H-Brücken aus je 2× IR2104 und 4 N-FETs, Inline-Strommessung mit
INA240A2, Fensterkomparator und Latch je Kanal, beide Stackverbinder.

**Was der Schaltplan noch nicht ist:**

- **Nicht geprüft im Sinne einer Schaltungsreview.** Werte sind gerechnet, aber die
  Regler sind noch nicht gegen die Hersteller-Referenzlayouts abgeglichen.
- **Pinbelegungen der ICs gegen die Datenblätter prüfen** — insbesondere INA240A2D,
  dessen KiCad-Symbol zwei GND-Pins gestapelt führt.
- **Die Darstellung ist zweckmäßig, nicht schön.** Jedes Bauteil hängt über kurze
  Stummel an globalen Labels. Das ist netzlistenidentisch mit einem gezeichneten Plan
  und lässt sich in KiCad frei umarrangieren, ohne die Verbindungen zu verlieren.

**Layout:** Platzierung generiert, Zonen gefüllt, **985 Segmente und 102 Vias**
geroutet, keine Kupferfehler. Offen sind **43 Verbindungen im Motor- und
Leistungsteil** (SW-Knoten, Gate-Netze, `24V_PROT`). Der Autorouter konvergiert
dort nicht mehr — und soll es auch nicht: Diese Pfade sind laut
[`docs/05`](../../docs/05-manufacturing.md) Abschnitt 3 **von Hand** zu ziehen,
kurz und breit, Buck-Schleifen nach Hersteller-Referenzlayout, Sternpunkt
AGND/PGND über R12. Erst danach greift das DRC-Gate von `gen_fab.py`.

Offene Bauteilposition: der N-Kanal-MOSFET (Punkt 8 in
[`docs/06`](../../docs/06-open-decisions.md)) — er hängt am noch nicht gemessenen
Blockierstrom.

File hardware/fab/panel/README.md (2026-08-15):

# Fertigungsnutzen

> **Gemischte Geometrie seit dem 16.08.2026.** Bottom und Mid sind Kreise
> Ø 52, das Top-Board ist ein abgerundetes Quadrat 47 × 47 (Punkt 48). Der
> Generator behandelt beide Formen: die Kreise über die Bogenlogik, das Quadrat
> über eine Parallelkurve seiner Kontur. **173,4 × 64,4 mm = 112 cm²**, vier
> Stege je Platine.

`switchstack_panel.kicad_pcb` enthält alle drei Platinen in einer Datei —
Bottom, Mid und Top nebeneinander, gehalten von Trennstegen in einem Rahmen.

> **Erzeugt, nicht gezeichnet.** Diese Datei ist ein Build-Ergebnis wie die
> Gerber. Sie wird nie von Hand bearbeitet, sondern neu erzeugt:
>
> ```bash
> /Applications/KiCad/KiCad.app/Contents/Frameworks/Python.framework/Versions/3.9/bin/python3 \
>     tools/gen_panel.py
> ```
>
> Änderungen gehören in die drei Quellprojekte unter `hardware/`. Der Nutzen
> greift beim nächsten Lauf darauf zu.

## Warum überhaupt ein Nutzen

KiCad kennt nur ein Board je Projekt — das Handbuch zu 10.0 ist da eindeutig:
*„a project can only contain a single board."* Wer die drei Platinen in einer
Datei will, hat zwei Möglichkeiten: die Quellen verschmelzen, oder einen Nutzen
erzeugen. Das Verschmelzen kostet die Referenzbezeichner (alles müsste ein
Präfix bekommen) und die Möglichkeit, ein Board allein zu revidieren. Der
erzeugte Nutzen kostet nichts davon: Bauteil- und Netznamen bekommen ihr Präfix
erst hier drin, wo Eindeutigkeit gefordert ist.

| Ebene | Präfix Referenz | Präfix Netz |
|---|---|---|
| Bottom | `B_` | `BOT_` |
| Mid | `M_` | `MID_` |
| Top | `T_` | `TOP_` |

## Geometrie

| | |
|---|---|
| Nutzengröße | **178,4 × 64,4 mm** (115 cm²) |
| Anordnung | drei Kreise Ø 52,0 in einer Reihe, Teilung 57,0 mm |
| Fräsfuge | 2,2 mm (Fräser 2,0 mm plus Toleranz) |
| Rahmen | 4,0 mm ringsum |
| Stege | 4 je Platine, 4,0 mm breit, auf den Diagonalen |
| Mausbisse | 5 × Ø 0,6 mm je Steg, 0,45 mm außerhalb der Platinenkante |

Die Reihe ist die flächengünstigste Anordnung: 115 cm² gegenüber 129 cm² beim
Dreieck (zwei oben, eine unten). Unter 100 × 100 mm ist nichts zu holen — drei
Kreise Ø 52 brauchen mathematisch mindestens ein Quadrat von 102 mm
Kantenlänge, und das ohne jede Trennfuge.

Die Stege liegen auf den **Diagonalen**, weil alle vier Achsrichtungen belegt
sind: 0° und 180° sind die Befestigungsbohrungen, 90° ist beim Top-Board der
überstehende USB-C-Stecker, 270° beim Mid-Board der Antennen-Keepout.

## Trennen — das ist Handarbeit

Runde Platinen lassen sich nicht ritzen. Nach dem Ausbrechen steht am Steg ein
Grat von etwa **0,5 mm** über. Der muss verputzt werden, bevor die Platine in
die Dose geht: Ø 52 in einer Dose mit 55–57 mm lichter Weite lässt 1,5–2,5 mm
Luft, ein unbearbeiteter Nub kann davon die Hälfte fressen.

Die Perforation liegt bewusst **außerhalb** der Platinenkante. Genau auf der
Kante würde jede Bohrung in den Randabstand des Kupfers ragen — das waren im
ersten Entwurf 480 zusätzliche Clearance-Fehler. Der Preis dafür ist genau
dieser Grat.

## Designregeln

Ohne eigene Projektdatei fiele der Nutzen auf KiCads Standardwerte zurück und
meldete Fehler, die keine sind — das Bottom-Board ist mit 0,15 mm Clearance
geroutet, die Vorgabe lautet 0,2 mm. `gen_panel.py` erzeugt deshalb auch
`switchstack_panel.kicad_pro` und überträgt die Regeln aus den drei
Quellprojekten: jede Ebene behält über ein Netzklassenmuster (`BOT_*`, `MID_*`,
`TOP_*`) ihre eigenen Werte, die Mindestvorgaben werden zur durchlässigsten
Variante zusammengefasst.

## Stand der Prüfung

Neu erzeugt am 15.08.2026, nachdem das Top-Board umgebaut wurde (Klinke auf
6 Uhr, ToF auf 12 Uhr, USB-C-Drehung korrigiert). Der DRC des Nutzens ist
**deckungsgleich mit der Summe der Einzelboards**:

| Klasse | Anzahl | Was dahintersteckt |
|---|---:|---|
| `clearance` | 28 | Pad-zu-Pad **innerhalb** des USB-C-Footprints: 0,85 mm Raster gegen 0,15 mm Vorgabe. Eine Regel-gegen-Footprint-Frage, kein Layoutfehler |
| `copper_edge_clearance` | 2 | Platzhalter-Footprint der Klinkenbuchse (Punkt 30) |
| `unconnected_items` | 342 | erwartet: **Mid und Top tragen keine Leiterbahnen**, Bottom ist zu ≈ 85 % geroutet, und die Masseflächen werden erst beim Öffnen in KiCad gefüllt |

Was der Nutzen **zusätzlich** meldet, sind Silkscreen-Überlappungen: durch die
Präfixe werden die Bezeichner länger. Das ist kosmetisch und betrifft keine
Kupferlage.

**Vor der Bestellung:** Mid und Top routen, Masseflächen füllen, DRC auf null
Kupferfehler bringen und die Fertigungsanweisung um das Verputzen der Stege
ergänzen.

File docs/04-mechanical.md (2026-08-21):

# 04 – Mechanik

## 1. Grunddaten

| Parameter | Wert |
|---|---|
| Leiterplattenform | Kreis |
| Durchmesser | **Ø 52,0 mm** (Radius 26,0 mm) |
| Leiterplattendicke | **1,0 mm** |
| Unterputzdose | massiv, Ø 60 mm außen, **61 mm tief** |
| **Abdeckrahmen** | **Busch-Jaeger 1721-914, Busch-balance SI, 1-fach** (2CKA001725A1555) |
| Stack-Abstand Bottom ↔ Mid | **10 mm** |
| Stack-Abstand Mid ↔ Top | **10 mm** — bewusst gleich wie unten |

> **Revision: Ø 55,0 mm → Ø 52,0 mm.**
> Eine Gerätedose mit 60 mm Außendurchmesser hat je nach Hersteller nur etwa
> 55–57 mm lichte Weite, und im Inneren sitzen Schraubdome und Verstärkungsrippen.
> Eine Ø-55-mm-Platine wäre damit im besten Fall eine Presspassung ohne jede
> Toleranz — und beim Einbau von drei gestapelten Platinen mit Steckverbindern
> gibt es kein Nachjustieren.
>
> Ø 52,0 mm lässt ringsum 1,5–2,5 mm Luft. Das ist der Wert, mit dem die
> KiCad-Templates erzeugt wurden.
>
> **Vor dem Layout-Freeze die reale Dose ausmessen.** Ist mehr Platz vorhanden,
> ist die Änderung eine Zeile: `BOARD_DIAMETER` in
> [`../tools/gen_boards.py`](../tools/gen_boards.py) und Skript neu laufen lassen.

## 1b. Der Abdeckrahmen ist festgelegt

Verwendet wird der **Busch-Jaeger 1721-914** (Bestellnummer 2CKA001725A1555),
Serie *Busch-balance SI*, 1-fach, alpinweiß. Damit sind zwei Maße keine
Annahmen mehr:

| Maß laut Herstellerangabe | Wert | Folge für dieses Projekt |
|---|---|---|
| Einbaumaß (Fenster) | **55 × 55 mm** | Die Frontplatte mit 54,6 × 54,6 mm passt mit 0,2 mm Luft je Seite — das bisher angenommene 55er-Maß ist bestätigt |
| Außenmaß | **81 × 81 mm** | Die Tragring-Ohren der Platte sind 76 mm breit und verschwinden vollständig hinter dem Rahmen (2,5 mm Überdeckung je Seite) |
| Tiefe | 12 mm | sitzt vor der Wand, geht **nicht** ins 61-mm-Tiefenbudget |
| Bohrungsöffnung | 71 mm | deckt die Ø-60-Dose sicher ab |
| Befestigung | „Klemmbefestigung" | **Das ist die offene Stelle — siehe unten** |

### Was am realen Rahmen zu messen ist

Der Rahmen hält durch Klemmung, und die Herstellerangaben sagen nicht, *woran*.
Bei den SI-Serien greifen die Rastnasen üblicherweise am Tragring, nicht an der
Zentralscheibe — unsere Frontplatte ersetzt aber den Tragring durch zwei
angeformte Ohren und bietet den Rastnasen damit möglicherweise nichts zum
Greifen. Das entscheidet, ob die Platte überhaupt so montierbar ist, und gehört
zum Testdruck (Punkt 25):

1. **Woran rastet der Rahmen?** Innenkontur der Rastnasen ausmessen und
   prüfen, ob die Platte dort Material anbieten muss.
2. **Hat das 55er-Fenster vorn einen umlaufenden Absatz**, der die
   Zentralscheibe hält? Dann übernimmt er die Halterung, und die Platte braucht
   nur die richtige Dicke an der Kante.
3. **Eckradius des Fensters** gegen `plate_corner_r` = 2,0 mm — ein anderer
   Radius zeigt sich als Spalt in den Ecken.
4. **Freiraum für den Tastenüberstand:** Die Sicheln stehen 0,8 mm vor der
   Sichtfläche; sie liegen bei r ≤ 26,2 mm und damit sicher im 55er-Fenster,
   dürfen aber nicht an einem Innenabsatz des Rahmens streifen.

## 1c. Frontkonzept: Zentralscheibe statt eigener Platte

**Festgelegt am 15.08.2026.** Die Sichtfläche ist keine Eigenentwicklung mehr,
sondern die **Busch-Jaeger Zentralscheibe 6435-914** (2CKA006430A0402) mit dem
Aufdruck „Pfeile und OK". Sie gehört systemisch zum Bedienelement 6456-101 und
wird auch für Raumthermostat 1098 U-101 und CO₂-Sensor 1091 U verwendet.

| Zielhülle laut Datenblatt 6456-101 | Wert |
|---|---|
| Korpus | **54 × 54 × 23 mm** |
| Display | **1,68″**, hochauflösend, mit Hintergrundbeleuchtung |
| Bedienung | vier Tasten, Symbole *play / hoch / runter / OK* auf der Scheibe |

Damit entfallen die vier Sicheltasten und die gedruckte 54,6er-Platte; an ihre
Stelle tritt ein Adapter, der diesen Korpus nachbildet (Punkt 41). Das Display
wird rechteckig (Punkt 43), USB-C zeigt nach vorn und liegt unter der Scheibe
(Punkt 45).

### Die vier Durchbrüche

Alle vier liegen **auf den Diagonalen**, je einer zwischen einem Pfeil und einer
Taste — symmetrisch, und alle vier im 55er-Fenster und damit über der Dose:

> **Überholt am 18.08.2026 — aus vier Durchbrüchen sind zwei geworden.**
> Die vier Diagonalpositionen stammten aus der Zeit vor den Ecktastern; seit
> die dort stehen, ist auf der Diagonalen kein Platz mehr (siehe unten). Die
> neue Aufteilung nutzt den waagerechten Streifen zwischen Displayfenster und
> Platinenrand, der **10 mm hoch und über die ganze Breite frei** ist:
>
> | Durchbruch | Lage | Zweck |
> |---|---|---|
> | **oben** | (0 / −19), Schlitz 14 × 5 mm | **ToF und Raumsensor gemeinsam** |
> | **unten links** | (−10 / +19,4), rund 6 × 5 mm | **Sternanschluss**, JST GH |
>
> **Ein Loch für zwei Sensoren.** Der VL53L1X sitzt bei (−3,5 / −19), der
> SHT4x bei (+3,5 / −19) — 3 mm zwischen den Bauteilkanten. Näher wäre
> schlechter, und zwar aus zwei Gründen: Der ToF darf keine spiegelnde Fläche
> im Sichtfeld haben, sonst misst er Übersprechen statt Entfernung, und der
> Raumsensor darf die Eigenwärme des ToF nicht mitmessen. Bei 27° Öffnungs­winkel
> und 2,5 mm bis zur Scheibe ist der Messkegel dort erst 1,2 mm breit — 3 mm
> Abstand liegen sicher daneben.
>
> **Die Klinke sitzt exakt mittig — weil die USB-Kerbe an den linken Rand
> gewandert ist.** Zuerst lag sie unten und musste sich den 30-mm-Streifen
> zwischen den Ecktastern mit der Klinke teilen; die hätte dann 4 mm neben der
> Mitte sitzen müssen. Quergestellt passt die Buchse aber in den
> **Seitenstreifen**: Der ist zwischen Displayfenster (x = −16,35) und
> Boardrand 7,15 mm breit, und die Buchse ist quer nur 4,3 mm tief.
>
> Ihre Lage ist zwischen zwei Grenzen eingeklemmt und hat **0,75 mm Spiel**:
>
> | Grenze | ergibt |
> |---|---|
> | Mids Radius 26 erlaubt die Körperecke bis y = 12,63 | Mitte ≤ 8,48 |
> | Tops Befestigungsbohrung reicht bis y = 2,98 | Mitte ≥ 7,73 |
>
> Gewählt ist **8,4**. Die Kerbe misst 6,25 × 9,5 mm und braucht keine Öffnung
> in der Scheibe — sie liegt darunter verborgen. Sichtbar sind vorn also genau
> **zwei Löcher**: der Schlitz oben für ToF und Raumsensor, das Loch unten
> mittig für die Klinke.
>
> **Dafür entfällt der Reserve-UART auf dem Top-Board.** Er war ein
> DNP-Steckplatz; auf 47 × 47 mm mit Display, vier Tastern, zwei
> 40-poligen Stackverbindern, Klinke, ToF, Raumsensor und Randkerbe findet der
> Platzierer für ihn keine Stelle mehr. Die Signale `UART_AUX_TX/RX` liegen
> unverändert auf `J_STK_B` 18/20 und sind vom Mid-Board aus erreichbar.

| Position | Zweck |
|---|---|
| oben links | ~~ToF-Fenster (VL53L1X)~~ |
| unten links | ~~Klinkenbuchse Weihnachtsstern~~ |
| oben rechts | ~~Lüftungsschlitz Raumsensor~~ |
| unten rechts | ~~Lüftungsschlitz Raumsensor~~ |

### Warum nicht im Abdeckrahmen

Naheliegend wäre, Klinke und ToF durch den Rahmen zu führen — er hat 13 mm
Rand rings um das Fenster. Das geht nicht, und zwar aus Maßen, nicht aus
Geschmack:

```
Rahmenfenster 55 × 55        -> halbe Kante            27,5 mm
Dose Ø 60 aussen             -> lichte Weite 55…57 mm  -> Radius 27,5…28,5 mm
```

Die Fensterkante des Rahmens fällt also mit der Dosenwand zusammen. Alles
außerhalb — der gesamte Rand — liegt **auf der Wand**. Hinter einem Loch dort
ist Putz, keine Platine. Aufgenommen als Punkt 47.

## 1d. Messprotokoll F1–F13: Zentralscheibe und Abdeckrahmen

Diese Maße geben das Top-Layout und den Adapter frei. Ein Maßbild ist öffentlich
nicht zu bekommen, deshalb werden sie am realen Teil genommen. Benötigt werden
nur **Zentralscheibe 6435-914** und **Abdeckrahmen 1721-914** — der Einsatz
6422 U ist bequem, aber nicht nötig.

**Bezugssystem:** Blick auf die Sichtfläche. Ursprung ist die Mitte der
Zentralscheibe, **x nach rechts, y nach oben**. Weil die Mitte nicht direkt
messbar ist, wird alles gegen die **Plattenkanten** gemessen; die Umrechnung
mache ich. Messschieber, 0,1 mm genügt.

### A – Zentralscheibe, Sichtseite

| # | Maß | Warum |
|---|---|---|
| **F1** | Außenmaß Breite × Höhe, und die Dicke der Sichtfläche | Prüft die 55-mm-Annahme und gibt die Materialstärke für die vier Durchbrüche |
| **F2** | Gesamttiefe: Sichtfläche bis zur hintersten Kante (Rastnasen eingerechnet) | Obergrenze für alles, was zwischen Platine und Scheibe steht — Display, USB-C-Buchse, Klinke |
| **F3** | Fensterausschnitt: Breite × Höhe, dazu der Eckradius | **Bestimmt das Display** (Punkt 43) |
| **F4** | Lage des Fensters: Abstand linke Fensterkante ↔ linke Plattenkante, obere Fensterkante ↔ obere Plattenkante | Sitzt das Fenster mittig? Falls nicht, ist genau das die entscheidende Zahl |

### B – Die vier Symbolfelder

| # | Maß | Warum |
|---|---|---|
| **F5** | Je Symbol: Abstand seiner Mitte zur **linken** und zur **oberen** Plattenkante | **Entscheidet Punkt 42.** Liegen die vier auf den Achsen oder auf den Diagonalen? Daran hängt, ob die acht Taster wandern müssen — und damit das Bohrbild aller drei Boards |
| **F6** | Sind die Symbolfelder **beweglich**? Draufdrücken: federt es, klickt es, oder ist es starres Material? Gibt es Trennfugen oder Schlitze rings um das Feld? | Entscheidet, ob die Scheibe selbst die Taste ist oder ob der Adapter Tastenkappen tragen muss |
| **F7** | Falls beweglich: Breite × Höhe der beweglichen Fläche, und wo sie angebunden ist (umlaufender Steg, Filmscharnier auf einer Seite?) | Bestimmt, wo der Druck ankommt und wie viel Hub zur Verfügung steht |

### C – Zentralscheibe, Rückseite (das eigentliche Interface)

| # | Maß | Warum |
|---|---|---|
| **F8** | **Rastnasen:** Anzahl, Lage (Abstand zu den Plattenkanten), Höhe über der Rückfläche — und das **lichte Innenmaß zwischen gegenüberliegenden Nasen**, in x und in y | Das ist das Maß, auf das der Adapter geklemmt wird. Die wichtigste Zahl für Punkt 41 |
| **F9** | Umlaufender Kragen oder Rand auf der Rückseite: lichte Innenmaße und Tiefe | Der Adapter muss hineinpassen, ohne die Scheibe aufzudrücken |
| **F10** | **Druckstößel oder Dome hinter den Symbolfeldern:** vorhanden? Wenn ja Ø, Höhe über der Rückfläche und Lage | Falls vorhanden, sind **das** die Punkte, auf die unsere SMD-Taster müssen — dann ist F5 nur die Kontrollrechnung |

### D – Abdeckrahmen und Zusammenbau

| # | Maß | Warum |
|---|---|---|
| **F11** | Lichtes Fenstermaß des Rahmens und dessen Eckradius; Tiefe von der Sichtfläche bis zur Rückkante | Gegenprobe zu den 55 × 55 aus dem Katalog |
| **F12** | Scheibe in den Rahmen setzen: **Hält sie von allein?** Und wie tief liegt ihre Sichtfläche hinter der Rahmenvorderkante? | Klärt, ob der Rahmen die Scheibe hält oder der Adapter — und wie weit die Tastenfelder vorstehen dürfen |
| **F13** | Klemmelemente des Rahmens auf seiner Rückseite: Lage und lichtes Maß — worauf klemmt er? | Punkt 25: Der Adapter muss dem Rahmen anbieten, was sonst der Tragring bietet |

### Ergebnisse, gemessen am 16.08.2026

| # | Messwert |
|---|---|
| F1 | **55,2 × 55,2 mm**, Sichtfläche **1,0 mm** dick |
| F2 | Gesamttiefe **7,5 mm** |
| F3 | Fenster **32,7 × 27,0 mm**, Eckradius klein (noch offen) |
| F4 | links 10,3 · oben 13,8 → rechnerisch rechts 12,2 · unten 14,4 |
| F5 | Symbole (von links / von oben): ↑ 28,0/8,0 · ▷ 6,0/27,5 · ↓ 28,0/46,0 · OK 50,0/27,5 |
| F6 | **starr** — keine beweglichen Felder, keine Trennfugen. Auf der Rückseite kleine Kreuze |
| F7 | entfällt |
| F8 | **4 Rastnasen**, je eine mittig pro Kante, 1,0 mm breit und hoch, vorn angeschrägt 1,0 → 1,4 mm. **Lichtes Innenmaß 50,0 mm** |
| F9 | kein Kragen, nur die 1,0 mm starke Wand |
| F10 | **4 Kreuze, 3,2 × 3,2 mm, 1,5 mm hoch** — laut Foto an den **Ecken**, nicht bei den Symbolen |
| F11 | Rahmenfenster **56,00 mm** |
| F12 | Scheibe hält **nicht** von allein im Rahmen; Sichtfläche liegt **bündig** |
| F13 | je Innenseite zwei Doppelstege — eher Justierung als Halt |

### Was daraus folgt

Umgerechnet auf den Ursprung in der Plattenmitte (x rechts, y hoch):

| Merkmal | Lage |
|---|---|
| **Fenstermitte** | (−0,95 · +0,3) — praktisch mittig, minimal nach links |
| **Fensterdiagonale** | 42,4 mm = **1,67″** — deckt sich mit der Katalogangabe 1,68″ |
| Symbol ↑ | (+0,4 · +19,6), r = 19,6 |
| Symbol ▷ | (−21,6 · +0,1), r = 21,6 |
| Symbol ↓ | (+0,4 · −18,4), r = 18,4 |
| Symbol OK | (+22,4 · +0,1), r = 22,4 |
| **Fensterecke** | (±15,4 · ±13,8), r = **20,7** |

**Die Symbole liegen auf den Achsen, die Kreuze auf den Diagonalen.** Das ist
der wichtigste Befund: Gedrückt wird dort, wo die Beschriftung steht — die Kraft
kommt aber an den **Ecken** an. Die starre 1-mm-Platte hängt an vier Rastnasen
in den Kantenmitten und kippt beim Druck auf ein Symbol; die beiden benachbarten
Eckkreuze wandern dabei nach hinten.

Zwei Konsequenzen:

1. **Die Taster bleiben auf den Diagonalen.** Die Befürchtung aus Punkt 42 —
   Taster auf den Achsen, Kollision mit den Befestigungsbohrungen bei 0° und
   180°, Bohrbild aller drei Boards neu — ist damit **vom Tisch**. Die acht
   Taster sitzen heute bei r = 23,2 auf ±12° um die Diagonalen; sie müssen nur
   auf die Kreuzpositionen nachgezogen und von acht auf **vier** reduziert
   werden, denn ein Kreuz von 3,2 mm trifft genau einen Taster.
2. **Die Firmware muss Paare auswerten.** Vier Taster an den Ecken, vier
   Symbole an den Kanten: ↑ = oben links + oben rechts, ↓ = unten links + unten
   rechts, ▷ = oben links + unten links, OK = oben rechts + unten rechts. Jede
   Richtung ist über ihr Paar eindeutig. Das ersetzt die bisherige Annahme
   „vier Tasten, vier GPIOs, eine Taste pro Pin".

**Die vier Durchbrüche passen so nicht mehr.** Sie waren für die Diagonalen
geplant — dort sitzen jetzt die Taster. Auf der Diagonalen bleibt zwischen
Fensterecke (r = 20,7) und Platinenrand (r = 26,0) ein Band von 5,3 mm, in dem
zusätzlich das Kreuz und der Taster liegen. Für ein Ø-4,5-ToF-Fenster und eine
Ø-5,6-Klinke ist das zu wenig; die Lage der Durchbrüche ist neu zu bestimmen,
sobald die Kreuzpositionen vermessen sind.

### Display: der Ausschnitt trifft ein Serienpanel fast exakt

| | |
|---|---|
| Fenster | 32,70 × 27,00 mm |
| **1,69″ 240 × 280 (ST7789), quer** | aktiv **32,63 × 27,97 mm** |
| Passung | Breite **0,07 mm** Luft, Höhe 0,97 mm vom Fenster verdeckt |

Damit ist Punkt 43 praktisch entschieden: Das Panel füllt den Ausschnitt in der
Breite randlos und wird in der Höhe um einen halben Millimeter je Seite
beschnitten — genau das, was ein Fenster tun soll.

### Nachtrag 16.08.2026: die Kreuze liegen außerhalb der Platine

| Gemessen | |
|---|---|
| Kreuzmitten | **7,6 mm** von der oberen bzw. unteren Kante, **9,6 mm** von der linken bzw. rechten |
| Rahmentiefe (F11) | **12 mm** |
| Doppelstege im Rahmen (F13) | Innenmaß **70,0 mm** |

Umgerechnet liegen die vier Druckpunkte bei **(±18,0 · ±20,0)** — also auf
**r = 26,91 mm** unter 48°. Die Ø-52-Platine reicht bis r = 26,0.

> **Der Druckpunkt liegt 0,9 mm außerhalb der Leiterplatte.** Mit dem Taster
> selbst (3,9 × 2,9 mm) und 0,5 mm Randabstand müsste eine *runde* Platine bis
> r = 29,8 reichen, also Ø 59,7 — das passt in keine Dose mit 55–57 mm lichter
> Weite.

Der Grund ist strukturell, kein Rechenfehler: **Das Busch-Jaeger-System ist um
einen quadratischen Einsatz von 54 × 54 mm gebaut, und seine Tasten sitzen in
den Ecken. Ein Kreis hat keine Ecken.** Genau die 0,9 mm, die fehlen, sind der
Unterschied zwischen Quadrat und einbeschriebenem Kreis.

#### Konsequenz: das Top-Board wird eckig

Nur das Top-Board ist betroffen — Mid und Bottom bleiben rund und bleiben in der
Dose. Das Top-Board wandert **vor** die Dose, so wie es der BJ-Einsatz auch tut,
und wird zum abgerundeten Quadrat:

| Randbedingung | Wert |
|---|---|
| Taster muss abdecken bis | (20,4 · 22,4) → Mindestgröße **40,8 × 44,8 mm** |
| Rastnasen der Scheibe (innen 50,0) | Kante höchstens **25,0** von der Mitte |
| **Umgesetzt** | **47 × 47 mm**, Ecken R 4 — die Größe folgt aus der Tiefenkette, siehe Abschnitt 1e |

Das kostet den gemeinsamen Umriss der drei Boards, bringt aber zwei Dinge:
Die Taster sitzen ohne Umlenkung direkt unter den Kreuzen — kein Hebel, kein
bewegliches Druckteil, die Federung bleibt beim Taster —, und weil das
Top-Board die Dose verlässt, **wächst das Tiefenbudget für Mid und Bottom**.

Die Alternative wäre ein Adapter mit vier Hebeln, der den Druck von r = 26,9 nach
innen auf r ≤ 23 umlenkt. Das widerspricht der Kernregel aus
[`09-display-and-mcu.md`](09-display-and-mcu.md) Abschnitt 1b — gedruckte
bewegliche Teile ermüden, Metallkuppel-Taster nicht — und wird deshalb nicht
empfohlen. Aufgenommen als Punkt 48.

#### Und der Adapter wird zum Tragring

F13 sagt: Der Rahmen klemmt auf **70,0 mm**. Das ist Tragring-Maß. Die bisherige
Frontplatte hat Ohren mit **76 mm** Spannweite — die stünden den Klemmstegen des
Rahmens im Weg. Der Adapter muss dem Rahmen also eine Fläche von 70,0 mm
anbieten, mit den Schraublöchern weiterhin auf 60 mm (DIN 49073).

### Noch offen

- **Eckradius** des Fensters (F3) und des Rahmenfensters.
- Bestätigung, dass die Platte beim Druck auf ein Symbol um die Mitte **kippt**
  (dann sind die Tasterpaare wie in Abschnitt „Was daraus folgt" beschrieben).

## 1e. Die Tiefenkette — sie bestimmt Platinengröße und Adapter

Von der Sichtfläche der Zentralscheibe nach hinten gezählt:

| von … bis | was |
|---|---|
| 0,0 … 1,0 | Zentralscheibe, Sichtfläche (F1) |
| 1,0 … 2,5 | Druckkreuz auf ihrer Rückseite (F10) |
| 2,5 … 4,5 | SMD-Taster über der Leiterplatte |
| 4,5 … 5,5 | **Top-Leiterplatte** |
| 7,5 | Rastebene und hinterer Rand der Scheibe (F2) |

### Die Displayfläche im Besonderen

Dort gilt eine eigene Kette, denn das Panel liegt zwischen Platine und
Scheibe:

| von … bis | was |
|---|---|
| 0,0 … 1,0 | Zentralscheibe |
| 1,0 … 2,9 | **Luft, 1,90 mm** — hier sitzt die Schaumdichtung |
| 2,9 … 4,5 | **Panel ER-TFT1.69-3**, 1,60 mm |
| 4,5 | Klebefuge, 0,1 bis 0,2 mm |
| 4,5 … 5,5 | Top-Leiterplatte |

**Befestigt wird geklebt, nicht geklemmt.** Doppelseitiges Band umlaufend auf
den Rand außerhalb der aktiven Fläche — **2,40 mm** an den langen Seiten,
**1,05 mm** an den kurzen. Die Schaumdichtung in den 1,90 mm davor drückt das
Panel zusätzlich an und hält Staub ab, **darf aber nicht die Befestigung
sein**: Die Zentralscheibe ist bewusst abnehmbar, damit man an USB kommt —
ein nur geklemmtes Panel fiele beim Abnehmen heraus.

**Die Vorderseite unter dem Panel ist im Layout gesperrt** (`block_f` in
`gen_layouts.py`). Das war nötig, weil dort zunächst die beiden
Stackverbinder standen — 8 mm hoch, mitten unter der Klebefläche. Sie liegen
jetzt auf der Rückseite, wo sie ohnehin hingehören, ebenso die FPC-Buchse.

> **Und eine dritte, am 18.08.2026 dazugekommen: die USB-C-Buchse passt hier
> nicht.** Zwischen Platinenvorderseite (4,5) und Sichtfläche liegen 4,5 mm,
> davon gehören 1,0 mm der Scheibe selbst und 1,5 mm ihren Druckkreuzen —
> nutzbar sind rund **3,5 mm**. Eine stehende USB-C-Buchse baut 7 bis 9,25 mm
> (GCT USB4115: H = 9,25 mm laut Datenblatt); keine Bauform liegt unter 7 mm.
> Sie hätte die Zentralscheibe durchstoßen, und liegend hätte sie radial nach
> außen gegen die Adapterwand gezeigt.
>
> Die Buchse steht deshalb jetzt auf dem **Mid-Board** bei (3,5 / 20,3) und
> greift durch eine **offene Randkerbe** des Top-Boards nach vorn. Zwischen
> Mids und Tops Oberseite liegen 10,0 mm — dort passt sie bequem. Gesteckt
> wird weiterhin frontal, sobald die Zentralscheibe ab ist.
>
> Die Kerbe misst 11,0 mm in der Breite und reicht von y = 16,8 bis zur
> Boardkante bei 23,5. Offen statt geschlossen, weil ein Fenster einen Steg
> von einem halben Millimeter stehen ließe — der bricht beim Nutzentrennen.
> Der Buchsenkörper liegt mit −0,65…7,65 / 18,15…22,45 vollständig darin, mit
> 3,3 mm Abstand zum Displayfenster, 4 mm zur Klinkenbuchse und 9 mm zum
> Ecktaster.
>
> Der Adapter musste mitziehen: Seine zentrale Durchführung endete bei 21,5
> und ist an dieser Stelle bis 24,0 verlängert. Damit ist er **nicht mehr
> punktsymmetrisch** — die Freistellung liegt auf der 6-Uhr-Seite, dieselbe
> Richtung wie Kerbe und Klinkenbuchse.

Zwei Folgerungen, die nicht verhandelbar sind:

**Die Rastebene liegt hinter der Leiterplatte.** Der Schnapprand des Adapters
steht also hinter ihr und trägt sie zugleich — er ist Rastglied und Auflage in
einem.

**Das Top-Board misst 47 × 47 mm.** Die Scheibe rastet auf lichte 50,0 (F8),
der Rand ist außen 49,8, und bei 1,4 mm Wand bleiben innen genau 47,0. Nach
unten begrenzen die Taster: Sie stehen auf (±18 · ±20), reichen mit Footprint
bis 22,2, und mit Randabstand braucht es mindestens 45,4 — also liegt 47,0
zwischen zwei harten Grenzen und ist keine gewählte Zahl.

Der Adapter ist damit vollständig bestimmt und erzeugt:
[`../mechanical/adapter.py`](../mechanical/adapter.py), Selbsttest bestanden.
Flansch 70 × 70 × 2,5 (darauf klemmt der Rahmen, F13), Schnapprand 49,8 mit
zurückspringendem Rastraum, Platinentasche 47,4, zentrale Durchführung 43 × 43
für die beiden Stackverbinder, Schraubschlitze auf 60 mm. Gesamthöhe 10,0 mm.

Board-Outline in KiCad: Kreis auf `Edge.Cuts`, Mittelpunkt (0,0), Radius 26,0 mm
— **außer TOP**, das ist ein abgerundetes Quadrat 47 × 47 mit R 4.
Board-Dicke über *Board Setup → Physical Stackup*.

Die drei Boards werden nicht von Hand gezeichnet, sondern von
[`../tools/gen_boards.py`](../tools/gen_boards.py) erzeugt. Damit ist ausgeschlossen,
dass Outline oder Bohrbild zwischen den Boards auseinanderlaufen.

## 2. Koordinatensystem

Ursprung (0,0) liegt im **Mittelpunkt der Leiterplatte**, auf allen drei Boards identisch.

> **Achtung — Y-Richtung.** KiCad zählt Y im PCB-Editor nach *unten*. Ein Punkt, der
> mathematisch bei y = +19,919 liegt, wird in KiCad als y = −19,919 eingegeben. Die
> Tabelle unten führt beide Konventionen, um Verwechslungen auszuschließen.

**Frontorientierung:** Für alle drei PCBs gilt dieselbe Definition —
mathematisch **+Y = Frontreferenz „oben“** (12-Uhr-Position). Der Hochstrom-Steckverbinder
sitzt entsprechend im Bereich **−Y (unten)** des Bottom-Boards. Diese Orientierung ist auf
jedem Board durch eine Silkscreen-Markierung an der 12-Uhr-Position kenntlich zu machen.

## 2b. Befestigungskonzept v2 — verschraubt statt nur gesteckt (19.08.2026)

Bisher hielt der Stapel allein durch die Steckverbinder, und der Adapter
übernahm Tragring UND Scheibenträger in einem Teil. Beides ist aufgeteilt:

```
Dose
 └─ schrauben (60 mm) ─ TRAGRING-ADAPTER  (mechanical/tragring.py, gedruckt)
                          ├─ Abdeckrahmen klemmt mit den Doppelstegen darauf
                          ├─ zentriert den Adapter-Basisring in der 50,6er Öffnung
                          └─ Kabeldurchlass für den Magnetkontakt
Bottom ═ Hülse M2,5×10 ═ Mid ═ Hülse M2,5×10 ═ Top
                                                └─ liegt in der Tasche des
                                                   SCHEIBENADAPTERS (adapter.py)
                                                    └─ Zentralscheibe rastet darauf
```

**Der Kraftfluss beim Anziehen der beiden Schrauben von vorn — korrigiert
am 20.08.2026:** Schraubenkopf → Top-Board → Adaptertasche →
**Adapter-Drucklippe** → Rahmensteg → Tragring-Adapter → Dose.

Die erste Fassung führte die Kraft über die Zentralscheibe. Das war falsch,
und der Einwand kam aus der Anschauung des echten Teils: **Die 6435-914 ist
das Bedienelement** — die ganze Scheibe bewegt sich, um die Ecktaster zu
drücken. Ein bewegliches Teil kann keine Klemmkraft tragen. Deshalb hat der
Scheibenadapter jetzt eine **Drucklippe** an der Vorderkante (51,6, an den
Kantenmitten für die Rastnasen unterbrochen), die den Rahmensteg direkt
gegen den Tragring presst. Die Scheibe wird zum Schluss nur aufgeclippt und
bleibt kraftfrei beweglich. **Messpunkt F15:** Steg-Innenmaß des Rahmens
(Lippe muss darüber greifen) und Innenmaß des Scheibenkorpus (Lippe muss
darunter bleiben) — 51,6 ist ein Platzhalter zwischen beiden Annahmen.

> **DIE KETTE — neun Stationen, von hinten nach vorn.** So und nur so
> steht sie in jeder Zeichnung und jeder Ansicht (Festlegung des Nutzers
> vom 21.08.):
>
> **1** Feldstecker → **2** Gehäuse-Becher → **3** Bottom → **4** Mid →
> **5** Tragring → **6** Abdeckrahmen → **7** Scheibenadapter →
> **8** Top-Board → **9** Zentralscheibe
>
> Displaypanel und Schaumdichtung sind **keine** eigenen Stationen: Sie
> sind vor der Montage auf das Top-Board geklebt bzw. aufgelegt und
> gehören zu Station 8. Die Handgriffe unten folgen derselben Kette; nur
> der Feldstecker wird praktisch erst angesteckt, wenn die Kartusche
> verschraubt ist — räumlich bleibt er das hinterste Glied.

**Montagereihenfolge — Kartusche, Fassung vom 20.08.2026 (abends).** Die
erste Fassung begann mit dem Tragring in der Dose (unbaubar: Ø 52 passt
nicht durch die 50,6er Öffnung), die zweite schob die Boards lose in die
Dose und setzte den Tragring danach. Auch das ist überholt, seit der
Becher da ist: Die Boards wohnen im **Becher unter dem Tragring** und
gehen mit ihm zusammen als **eine Kartusche** in die Dose.

1. **Mid zwischen die Hülsen schrauben.** Untere Hülsen (M2,5 × 6,
   Buchse/Buchse) auf Bottom auflegen, Mid darüber, obere Hülsen
   (M2,5 × 6, **Stift/Buchse**) von vorn durch Mid in die unteren —
   ihr Gewindestift klemmt Mid. Bottom liegt noch lose an.
2. **Board-Paar in den Becher legen.** Bottom voran auf die vier
   Auflagebosse (Oberkante z = 0); USB-C zeigt zur 9-Uhr-Seite.
3. **Kartusche verschrauben:** zwei **M2,5 × 14** von hinten durch den
   Becherboden und seine Führungsrohre, durch Bottom (H1/H2) in die
   unteren Hülsen — Becher, Bottom und Mid sind jetzt EIN Teil
   (Konzept v3; das Bajonett ist Geschichte, die Dose hat vier Dome).
   Länge gerechnet: Weg 9,7 (Boden 1,5 + Hohlraum 6,9 + Board 1,0 +
   Luft) plus ≥ 4 Gewinde = 13,7 — eine 16er könnte in der 9er-Hülse
   aufsetzen, falls deren Gewinde kürzer als 6,3 ist.
4. **Feldstecker anstecken.** Die gecrimpte, in der Dose vorverdrahtete
   Micro-Fit-Leiste klickt von hinten durch den Stecker-Tunnel der
   Becher-Rückwand an Bottom.
5. **Tragring lose auflegen** (die Öffnung fädelt über die oberen
   Hülsen, Luft 3,8, und die USB-C-Buchse, Luft 2,1), dann **Kartusche
   samt Ring in die Dose schieben** und mit den Geräteschrauben auf
   60 mm festschrauben — erst sie machen Ring und Kartusche zur
   Einheit.
6. **Abdeckrahmen auf den Tragring klemmen** — er sitzt noch lose.
7. **Magnetkontakt-Kabel** aus der unteren Rahmenleiste durch den
   Kabeldurchlass des Tragrings nach innen führen und in J6 auf der
   Top-Rückseite stecken (liegende Buchse, Öffnung zur Kerbe).
8. **Top-Board in den Scheibenadapter**, aufsetzen, zwei Schrauben M2,5
   von vorn durch H1/H2 in die oberen Hülsen. Der Adapter taucht durch
   die Tragring-Öffnung, wird von ihr zentriert und presst mit der
   Drucklippe den Rahmensteg gegen den Tragring — jetzt erst sitzt der
   Abdeckrahmen fest.
9. **Zentralscheibe aufrasten** — nur noch das: Sie hält nichts und
   presst nichts, sie ist das bewegliche Bedienelement.

**Die Steckverbinder tragen seitdem nichts mehr.** Sie sind rein elektrisch;
Punkt 23 (durchsteckbarer Stapelverbinder) verliert dadurch seine mechanische
Bedingung und reduziert sich auf die Frage nach einem elektrisch passenden
Paar mit 10 mm Stapelhöhe.

**Maßvorbehalte, in den Testdruck aufzunehmen:** die Klemmhöhe der
Doppelstege am 70er-Kantenmaß (F13) und neu **F14**: Ist der Abdeckrahmen
unten mittig **hohl** — mindestens Ø 12 frei und ≈ 9 mm tief? Dort sitzt der
Einschraubkörper des Magnetkontakts (DCX-909: Gewinde Ø 8, Länge 8,5); hinter
dem Rahmenrand ist Putz, der Körper muss also vollständig in den Hohlraum des
Rahmens passen.

## 2c. Das Gehäuse — ein Becher, der in den Tragring rastet (20.08.2026)

`mechanical/gehaeuse.py` kapselt Bottom und Mid: Ein Becher (Ø 54,6 außen,
Wand 1,1) geht von hinten über die beiden Boards, die Rückwand hat ein
Tunnel-Fenster für die Feldstecker-Leiste — sie bleibt als einziges von
hinten zugänglich. Vier Auflagebosse tragen das Bottom-Board; gedruckt wird
der Becher zusammen mit dem Tragring.

**Verbindung v3: verschraubt, kein Bajonett (21.08.).** Radiale Haken
scheiterten dreifach (Diagonalen: Öffnungsecken bis r 35,8; außen die
Dose; innen der Basisring), und das Bajonett starb doppelt: Seine Zapfen
standen auf der weggefensterten Wand (zwei von drei schwebten im STL),
und die gemessene Dose hat Dome auf **allen vier Achsen** — es gibt kein
tragfähiges Band mehr. Jetzt halten die zwei Hülsenschrauben der
H1/H2-Achse die Kartusche: M2,5 × 14 von hinten durch den Becherboden,
durch Führungsrohre und Bottom in die unteren Hülsen. Der Tragring liegt
lose auf dem Becherrand.

**Die Dome (F16 gemessen):** Dose 58 licht, über die Dome 54 — die
Ø-6-Pfosten sitzen auf allen vier Achsen. Der Becher (außen 54,6) hat
1,7 mm Luft und vier Fenster à 10; durch sie schaut die Platinenkante.

**F16 im Detail — das Messprotokoll (mit Messschieber, an der echten
Dose):**

| # | Was | Annahme | **gemessen 21.08.** |
|---|---|---|---|
| F16a | Lichte Weite vorn am Rand | 55,0 | **58,0** |
| F16b | Lichte Weite in ~20 mm Tiefe | 55,0 | **58,0** |
| F16c | Weite über die Schraubdome | ~54 | **54,0** |
| F16d | Breite eines Doms, tangential (→ Fensterbreite) | 16 | **Ø 6** |
| F16e | Tiefe: Dosenrand bis Rückwand innen | 61 | **60,0** |
| F16f | Kabeleinführungen | mittig hinten | **seitlich, ~50 mm tief** |
| F16g | Dosentyp | — | — |

**Folgen der Messung:** Der Becher (außen 54,6) hat **1,7 mm Luft**
statt 0,2 — kein Hebel nötig, die Boards bleiben Ø 52. Die Dome sind
**Ø-6-Rundpfosten bis r 27 auf ALLEN VIER Achsen** (12/3/6/9 Uhr,
Nutzerbefund 21.08.) — der Becher bekommt vier Fenster à 10 statt zwei
à 16. Die Tiefe schrumpft auf 60 (Reserve ≈ 16). Die seitlichen
Kabeleinführungen bei ~50 mm Tiefe sind günstig: Der Kabelbogen muss
nicht mehr hinter den Stecker, er kommt von der Seite.

**Der Adapter trägt wieder — drei Einwände des Nutzers vom 21.08.**
„Der Adapter muss ja trotzdem geschlossen sein, sonst hält ja nichts",
„die Aussparungen sind doch genau invers, dort hält doch die
Zentralscheibe" und „es muss sichergestellt sein, dass der
Scheibenadapter auch wirklich auf den Tragring drückt". Alle drei
trafen, alle drei sind behoben:

1. **USB-Freistellung endet an der Auflage.** Sie lief über die volle
   Bauhöhe und trennte den tragenden Ring an der linken Kante komplett
   auf. Die Buchse endet aber bei Modellhöhe 4,75 und liegt dort mit
   x = −23,2 längst **innerhalb** der Platinentasche (deren Rand erst
   bei 23,7 beginnt) — oberhalb der Auflage braucht sie keinen
   Millimeter. Tasche, Lippe und Kragen sind jetzt umlaufend
   geschlossen.
2. **Nasenpass 14,0 → 3,0 mm — und ein Rastnocken dahinter.** F8 misst
   die Rastnasen mit **1,0 mm Breite**; der Platzhalter war
   vierzehnfach überdimensioniert. Die Durchfahrt bleibt nötig — die
   Nasen müssen an Lippe und Kragen vorbei —, ist aber jetzt ein
   schmaler Schlitz statt eines großen Lochs.

   **Und der eigentliche Halt fehlte bisher ganz (Punkt 67).** Der
   umlaufende Rand ist 49,8, das lichte Nasenmaß 50,0: Die Nase fuhr mit
   0,1 mm Luft darüber und griff hinter **nichts** — die Scheibe hätte
   nur lose aufgelegen. Auf den Punkt gebracht hat es der Nutzer: „die
   Zentralscheibe muss sich praktisch in diesen Aussparungen
   rüberklicken." Jetzt sitzt an jeder der vier Kantenmitten — genau
   dort, wo F8 die Nasen misst — ein **Rastnocken 50,6** (6,0 breit,
   0,7 hoch) am hinteren Ende der Schulter. Die Nase weitet sich beim
   Aufschieben um **0,30 mm je Seite** auf (ihre eigene Auflauffase
   1,0 → 1,4 aus F8 übernimmt das) und fällt dahinter in den Rastraum.
   Erst dieser Nocken macht aus dem Aufstecken ein Einrasten; der
   Selbsttest prüft den Hintergriff seither auf 0,2…0,6 mm.
3. **Neuer Auflagekragen 52,0 × 0,8.** Er kragt auf der Vorderseite des
   Basisrings über die Tragring-Öffnung (50,6) und legt sich mit
   **0,70 mm je Seite** auf die Platte. Damit läuft die Kraft
   nachweisbar Schraube → Top-Board → Adapterauflage → **Kragen** →
   Tragring → Geräteschrauben → Dose — **unabhängig von F15**, dessen
   Rahmensteg-Maß weiter offen ist. Obergrenzen eingehalten: Der Kragen
   bleibt im Rahmenfenster (F11: 56,0) und hält 0,60 mm je Seite Luft
   zum Scheibenkorpus (innen 53,2). `pruefe_einbau.py` prüft die
   Auflage jetzt als eigene Materialprobe in der Kragenebene.

**Die y-Falle — drei Ausschnitte lagen spiegelverkehrt (21.08., mit
bloßem Auge gefunden: „warum hat der Tragring oben eine Aussparung?").**
KiCad zählt y **nach unten**, build123d und der STEP-Export **nach
oben**. Die gedruckten Teile hatten Layout-Zahlen direkt übernommen —
damit saßen **USB-Freistellung** (Adapter), **Kabeldurchlass**
(Tragring) und **Steckertunnel** (Becher) alle auf der falschen Seite.
Nachgemessen am exportierten Top-Board: Die USB-Randkerbe steht im
Layout bei y = +8 und im STEP bei y = −8 — Beweis geführt, nicht
vermutet. Der Steckertunnel war zusätzlich an einer veralteten
Position (−10,5 / 15,6 statt J1 bei 0,0 / 17,5).

Behoben, indem die PARAMS in Layout-Koordinaten **bleiben** (so bleiben
sie mit `gen_layouts.py` vergleichbar und die Zeichnungen, die sie
lesen, stimmen weiter) und die `build_*`-Funktionen beim Erzeugen mit
−y spiegeln; der Konventionsblock steht im Kopf aller drei Dateien.

**Warum das keiner der Selbsttests gemerkt hat — und was jetzt anders
ist:** Fenster und Prüfkörper kamen aus **derselben** Konstante, jede
Verschiebung hob sich auf. `mechanical/pruefe_einbau.py` liest die
Gegenstücke jetzt per `ast` aus `gen_layouts.py` (Feldstecker J1,
USB-Buchse J7, Kabelkerbe) und prüft sie boolesch gegen die gedruckten
Teile — die Teile müssen sich nach dem Layout richten, nicht umgekehrt.
Der Fehler war damit reproduzierbar (212 mm³ Stecker im Becherboden,
76 mm³ Buchse im Adapter), und die Prüfung ist grün, seit er behoben
ist.

**Warum Tragring und Scheibenadapter so filigran aussehen — und warum
das kein Fehler ist (21.08., Einwand des Nutzers):** Beide Teile sind
fast nur Wände, und **jede dieser Wandstärken ist von den
Busch-Jaeger-Schnittstellen diktiert**, nicht gewählt: Außen begrenzt
das Rastmaß der Zentralscheibe (50,0 → Rand 49,8), innen das Top-Board
in der Tasche (47,0 + 0,4 Spiel = 47,4) — dazwischen bleiben **1,2 mm
Wand**, mehr gibt die Geometrie nicht her. Die Drucklippe (51,6) folgt
dem Rahmensteg, die Ringdicke (2,0) der Klemmhöhe der Rahmen-Doppelstege
(F13). Verstärken lässt sich nur über das Material (PETG oder PC statt
PLA) und die Druckrichtung (flach, Lasten in der Ebene) — genau dafür
ist der Testdruck mit F13/F15 da. Der Tragring aus dem Originalsystem
ist zum Vergleich ~1 mm Stahlblech; unsere 2 mm Druck sind dagegen
schon die kräftige Fassung.

**Einbauprüfung gegen die gemessene Dose (21.08.,
`mechanical/pruefe_einbau.py`):** Die Dose aus F16 (58 licht, 60 tief,
vier Ø-6-Dome bis r 27) steht als Volumenkörper im Prüfwerkzeug; Becher,
Tragring, Adapter, beide Ø-52-Boards und der Feldstecker werden boolesch
dagegen geschnitten. Ergebnis: **BESTANDEN, kleinere Boards sind NICHT
nötig** — Board→Dom 1,0 Luft, Becher→Dose 1,7, Fensterrand→Dom-Sehne
3,7 je Seite. Ein Treffer wurde dabei gefunden und behoben: Der
Scheibenadapter endete 0,5 **unter** der Wandebene, seine Ecken
(Quadrat-Eckradius 35,2) drückten auf den runden Dosenrand — der
Flansch ist von 2,5 auf 2,0 gekürzt, der Adapter endet jetzt bündig
(stack.py 15,5). Dazu zählt `tools/stl_shells.py` die Schalen jeder
STL: je **eine** — nichts schwebt. Beide Werkzeuge sind die Lektion aus
dem Zapfen-Defekt in Werkzeugform.

**Der bestätigte Defekt und seine Auflösung — Konzept v3, verschraubt
statt Bajonett (21.08.).** Der Einwand „die Ränder hängen in der Luft"
traf: Zwei der drei Bajonettzapfen standen auf der weggefensterten Wand
und schwebten als lose Körper im STL. Mit Domen auf allen vier Achsen
ist das Bajonett auch nicht reparierbar — Zapfen und Ringschlitze
finden kein tragfähiges Band mehr (die Diagonalen blockiert die
quadratische Ringöffnung). Stattdessen fassen die zwei Schrauben, die
Bottom ohnehin von hinten in die unteren Hülsen halten, jetzt **durch
den Becherboden** (M2,5 × 14 statt × 6, Führungsrohre Ø 6 überbrücken
den Hohlraum): Becher + Bottom + Mid sind die verschraubte Kartusche.
Der Tragring liegt lose auf dem Becherrand und kommt mit den
Geräteschrauben an die Dose. Kein neues Teil, keine engen Toleranzen,
und die Rohre stützen Bottom zusätzlich auf der Schraubenachse.

Nach der Messung werden `gehaeuse.py` (Weite, Spiel, Fensterlage/-breite,
Tunnel), die Gegenproben in `tragring.py`, STL/STEP, Renderings und die
Doku in einem Durchgang nachgezogen. Fällt F16 großzügig aus, bekommt
der Becher mehr Luft statt 0,2 mm Passung; fällt er eng aus:

**Falls F16 eng ausfällt — Hebel in dieser Reihenfolge (20.08., nachts,
Einwand des Nutzers):** Der Becher steht mit 54,6 gegen die 55er-Annahme
rechnerisch auf Kante; ob das real reicht, entscheidet allein F16 (eine
60er-Dose hat nominell ~60 lichte Weite, die Annahme ist bewusst
pessimistisch). Wird es eng: **1.** Wand 1,1 → 0,8 und Spiel 0,4 → 0,3
(außen 53,7 — ein Parameter, ein Neudruck); **2.** Dome-Fenster
verbreitern (kostet Wandanteil, keine Elektronik); **3.** erst als
letzter Hebel die Boards verkleinern — Ø 52 → Ø 50 wäre ein Neulayout
beider runden Boards, und Bottom ist heute schon das vollste.

**Baugruppe ≠ Druckdatei.** Wer `switchstack_stack.step` sliced, sieht
den 70er-Ring frei über dem Becher schweben — im Einbau liegt er auf
Dosenrand und Wandputz, die das Modell nicht enthält. Gedruckt werden
**drei Einzelteile**, jedes flach: der Becher auf dem Boden (Wände
senkrecht, Zapfen minimal überhängend), der Tragring als Platte, der
Adapter auf der Lippenseite. Nichts davon braucht Stützen; verbunden
wird erst nach dem Druck, per Bajonett.

Montage ändert sich vorn nicht; neu ist Schritt 2b: Boards in den Becher,
Leiste durch das Rückwandfenster anstecken, Becher an den Tragring
bajonettieren — dann als Einheit in die Dose.

## 3. Befestigungsbohrungen

> **Bohrbild v2 — ZWEI Bohrungen statt drei.** Die Layout-Kollisionsprüfung hat
> einen Konflikt aufgedeckt, den die Frontplatten-Selbsttests nicht sehen konnten:
> Die Bohrungen bei 120°/240° lagen nur ≈ 2 mm neben den Sicheltasten-Stößeln
> (117°/243°) — Schraubenkopf und Taster kollidieren. Und auf r = 21,5 mm blockieren
> die Stackverbinder (um 45/135/225/315°), die ESP32-Antenne (um 90°) und der
> Leistungsstecker (um 270°) alle übrigen Kandidaten. **Frei sind genau 0° und 180°.**
> Die Verdrehsicherung übernehmen die beiden Stackverbinder selbst.

Zwei Bohrungen **M2,5 (Ø 2,7 mm)** auf Radius **21,5 mm**:

| Bohrung | Winkel | X [mm] | Y [mm] |
|---|---|---:|---:|
| H1 | 0° | +21,5 | 0,0 |
| H2 | 180° | −21,5 | 0,0 |

Quelle und Durchsetzung: `tools/gen_layouts.py` (Kollisionsmodell mit Kreisprüfung
für die Schraubenköpfe) und `tools/gen_boards.py`; beide aus denselben Konstanten.

## 4. Tiefenbudget

Verfügbar sind **60 mm** Dosentiefe (F16e gemessen; vorher 61 angenommen). Überschlägige Rechnung von der Dosenrückwand nach vorn:

| # | Element | Höhe [mm] | Kumuliert |
|---:|---|---:|---:|
| 1 | Kabelbogen / Steckraum hinter dem Bottom-Connector | 12,0 | 12,0 |
| 2 | Bottom-Connector inkl. gestecktem Gegenstück über PCB | 10,0 | 22,0 |
| 3 | Bottom-PCB | 1,0 | 23,0 |
| 4 | Bauteile Bottom-Oberseite + Stack-Abstand | **6,0** | 29,0 |
| 5 | Mid-PCB | 1,0 | 30,0 |
| 6 | Bauteile Mid-Oberseite + Stack-Abstand | **6,0** | 36,0 |
| 7 | Top-PCB | 1,0 | 37,0 |
| 8 | Adapter, Zentralscheibe, Rahmen | — | **außerhalb** |
| | **Reserve** | | **≈ 23,0** (auf 60 gemessen) |

> **Kurzer Stapel seit 21.08.2026 (Punkt 23).** Die Ebenen standen
> 9,0 mm frei auseinander, weil der Steckverbinder diese Höhe tragen
> sollte — bis die Recherche zeigte, dass es erhöhte 1,27-mm-Buchsen
> Jetzt sind es **6,0 mm** — und diese Zahl gibt der Verbinder vor,
> nicht die Mechanik. **Korrigiertes Steckmodell (22.08.):** Die 2,4 mm
> der Buchse sind ihr *Lötpin*, nicht die Einstecktiefe; beim Stecken
> stoßen die Kunststoffkörper aneinander. Es gilt **Spalt =
> Isolatorhöhe des Stifts + Buchsenhöhe** und **Eingriff = Pin-Überstand
> − (Spalt − Buchsenhöhe)**. Mit der 4,3er Buchse braucht der günstigste
> Stift (Isolator 1,5) mindestens 5,80 mm — bei 5,0 würde **jeder** am
> Markt verfügbare Stift klemmen. Nächste Standard-Hülsenlänge: 6,0,
> dort bleiben 1,35 mm Kontakteingriff.
> Die Bauteilhöhen wurden dagegen geprüft: unten steht als höchstes die
> Drossel SRP7028A mit 2,8 mm, oben das ESP32-Modul (3,2) und J6 (4,25),
> die sich örtlich **nicht** überlappen. Nebeneffekt: **9 mm mehr
> Reserve** — und Punkt 66 (Modell 9,0 gegen Doku 10,0) löst sich auf,
> weil Modell und Doku jetzt beide 5,0 sagen.

> **Revision 16.08.2026: das Top-Board verlässt die Dose.** Vorher standen hier
> 8,0 mm für „OLED, Taster, Frontpanel" und ≈ 9 mm Reserve. Seit der Umstellung
> auf die Busch-Jaeger Zentralscheibe sitzt das Top-Board **vor** der Dose im
> Adapter — dessen 10,0 mm Bauhöhe liegen vor der Wand, nicht in der Dose
> (Abschnitt 1e). Die Reserve steigt damit auf **rund 17 mm**.
>
> Das entschärft ausgerechnet die Position, die bisher am engsten war: Für den
> Leistungsstecker samt Kabelbogen (Positionen 1 + 2) ist jetzt Luft, ohne dass
> ein abgewinkelter Verbinder zwingend wird. Punkt 26 verliert damit seine
> Dringlichkeit — die Entscheidung bleibt, aber sie blockiert nichts mehr.

Zwei Positionen bleiben die kritischen:

- **Positionen 1 + 2 zusammen 22 mm** — mehr als ein Drittel der gesamten Tiefe geht für
  den Leistungsstecker und den Kabelbogen drauf. Ein **abgewinkelter Steckverbinder**
  oder eine Platzierung, die den Kabelbogen seitlich statt nach hinten führt, würde hier
  mehrere Millimeter freimachen. Das ist der wirksamste Hebel, falls das Budget später
  eng wird. Hinweis: ein stromstärkeres System wie Mini-Fit Jr. (siehe
  [`01-power-tree.md`](01-power-tree.md)) baut höher als Micro-Fit — Stromrating und
  Tiefenbudget hängen also direkt zusammen und müssen gemeinsam entschieden werden.
- **Position 4, Bauteile Bottom-Oberseite in 10 mm** — die in
  [`01-power-tree.md`](01-power-tree.md) genannten Bulk-Kondensatoren von 470–1000 µF
  passen als klassische Elkos hier nicht hinein. Realistisch sind mehrere niedrigbauende
  Typen, Polymer-Kondensatoren oder eine Platzierung auf der Unterseite neben dem
  Steckverbinder. Diese Entscheidung fällt beim Bottom-Layout und wirkt auf das gesamte
  Budget zurück.

Sobald die konkreten Bauteile feststehen, ist diese Tabelle mit realen Datenblattmaßen zu
aktualisieren.

## 5. Keepouts

| Bereich | Board | Regel |
|---|---|---|
| ESP32-Antenne | MID | kupfer- und bauteilfrei auf **allen** Lagen, Antenne zur Front |
| Befestigungsbohrungen | alle | Freihaltezone auf allen drei Boards deckungsgleich |
| Bottom-Connector | BOTTOM | Steck- und Entriegelungsraum berücksichtigen, nicht nur den Footprint |
| Stackverbinder | alle | Position auf allen drei Boards deckungsgleich |
| Frontelemente | TOP | USB-C, OLED, Taster, Stern-Stecker müssen zum Frontpanel passen |

Die Positionen von Befestigungsbohrungen und Stackverbindern müssen auf allen drei Boards
**exakt** übereinstimmen. Empfohlenes Vorgehen: mechanische Elemente einmal im
Bottom-Projekt festlegen und die Koordinaten aus dieser Datei in die beiden anderen
Projekte übernehmen, statt sie neu zu zeichnen.

## 6. Externer Bottom-Connector

Verriegelnder, vorkonfektionierbarer Steckverbinder mit PCB-Buchse und steckbarem
Kabelgegenstück.

**Festes logisches Pinout:**

| Pin | Signal |
|---:|---|
| 1 | 24V_IN+ |
| 2 | 24V_IN− |
| 3 | M1_A |
| 4 | M1_B |
| 5 | M2_A |
| 6 | M2_B |

Ausgangspunkt: Micro-Fit 3.0 2×3. **Vor der Footprint-Wahl ist zu prüfen, dass der
konkrete Steckverbinder Nenn- und Peakstrom sicher verträgt** — siehe die Analyse zum
Engpass an den Pins 1 und 2 in [`01-power-tree.md`](01-power-tree.md), Abschnitt 3.

## 6b. Durchbrüche in der Frontplatte

Die Sichtfläche darf nur an den vier Stegen zwischen den Sicheltasten
durchbrochen werden. Auf 3 und 9 Uhr liegen die Befestigungsbohrungen, es
bleiben **12 und 6 Uhr**. Jeder der beiden trägt **genau einen** Durchbruch:

| Durchbruch | Ø | Position (math, Y nach oben) | Zweck |
|---|---|---|---|
| **ToF-Fenster, 12 Uhr** | 4,5 vorn / 3,0 hinten | x = +5,0, y = **+22,5** | VL53L1X, konisch für den Sichtkegel |
| **Klinkenbuchse, 6 Uhr** | 5,6 mm | x = 0,0, y = **−22,5** | Weihnachtsstern, 2,5-mm-Klinke |

**Warum diese Aufteilung und nicht umgekehrt:** Der ToF muss nach oben — er soll
nach vorn und in die Fensteröffnung schauen, nicht auf die Fensterbank. Der
Steckplatz gehört nach unten, sonst hängt das Sternkabel quer über der Anzeige.
Vorher saßen beide Durchbrüche oben; die Klinke ist am 15.08.2026 nach unten
gewandert und liegt dort mittig, weil sie den Steg allein hat.

Die Stege sind von 9 auf **17 mm** verbreitert (`key_spoke_hw` 4,5 → 8,5) — und
zwar alle vier, weil `_ring_sketch` beide Rechtecke symmetrisch schneidet. Die
Sicheln schrumpfen dadurch von rund 70° auf 45°, die Stößel rücken von ±18° auf
±12° um die Diagonalen, sonst stünden die Taster den Durchbrüchen im Weg.

Der Kabelausgang Ø 4,5 mm im unteren Steg entfällt — der Stern wird gesteckt.
**Für die Klinkenbuchse gilt ein hartes Höhenmaß: 10,5 mm über der
Top-Leiterplatte**, mehr Platz ist bis zur Sichtfläche nicht da.

## 7. Stern-Ausgang

Separater zweipoliger Anschluss im Frontpanel, Ausgangspunkt **JST-PH 2-polig**.

| Pin | Signal |
|---:|---|
| 1 | 6V2_STAR |
| 2 | GND_STAR |

- Eigene kleine Absicherung, z. B. Polyfuse ≈ 0,3–0,5 A (Last real ≈ 80 mA)
- Lokaler Kondensator 10–22 µF am Stecker
- Die 6,2-V-Versorgung wird im Normalbetrieb aus 24 V erzeugt und hängt **nicht** vom
  USB-Port ab

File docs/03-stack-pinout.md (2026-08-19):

# 03 – Stackverbinder und Pinmapping

> **Verbindlichkeit:** Dieses Pinmapping ist ein ausgearbeiteter Vorschlag als
> Arbeitsgrundlage. Sobald es bestätigt ist, gilt es **identisch für alle drei Projekte**.
> Änderungen ab dann nur gemeinsam und mit Versionsvermerk am Ende dieser Datei.

## 1. Grundregeln

- Motor-Hochströme werden **nicht** über die Stackverbinder geführt. Sie bleiben
  vollständig auf dem Bottom-Board.
- Stackverbinder führen ausschließlich Kleinleistung und Signale.
- **Regeländerung v0.5 (18.08.2026):** Die vier Tastennetze liegen jetzt auf der
  **Außenreihe** des Verbinders, der ihrer Ecke am nächsten ist — `BTN1` auf
  `B1`, `BTN2` auf `A2`, `BTN3` auf `A40`, `BTN4` auf `B39`. Vorher lagen alle
  vier auf `B26…B29`, also auf vier benachbarten Kontakten der **Innen**reihe
  des **rechten** Verbinders, während ihre Taster in allen vier Ecken des
  Top-Boards sitzen — zwei davon links. `I2C_SCL`/`SDA` wanderten aus
  demselben Grund von `B6`/`B8` nach `B5`/`B7`.
- **Regeländerung v0.4/v0.5:** USB `D+`/`D−` laufen **nicht mehr** durch den
  Stack. Die USB-C-Buchse sitzt seit dem 18.08.2026 auf dem Mid-Board, wo auch
  der ESP32-S3 steht; `A34`/`A36` sind frei (`RSV_A3`/`RSV_A5`). Grund war die
  Bauhöhe: Über dem Top-Board sind bis zur Zentralscheibe 3,5 mm frei, eine
  stehende USB-C-Buchse baut 7 bis 9,25 mm. `USB_VBUS` bleibt auf `A18`.
- **Frühere Regeländerung v0.3:** USB `D+`/`D−` liefen **doch** durch den Stack
  (`J_STK_A` 34/36, benachbart, PGND daneben). Die alte Regel stammte aus der Zeit
  mit USB-UART-Baustein auf dem Top-Board; mit dem nativen USB des ESP32-S3 auf dem
  Mid-Board gibt es keine Alternative — und Full-Speed-USB (12 MHz) über zwei
  benachbarte Kontakte ist unkritisch. ESD-Schutz sitzt an der Buchse auf TOP.
- Zwei Verbinder: `J_STK_A` (Power/Motor) und `J_STK_B` (UI/Kommunikation).
- Ausgangspunkt: zwei **2×20-Steckverbinder mit 1,27 mm Raster**. Die konkrete Serie ist
  anhand Stackhöhe und Verfügbarkeit auszuwählen.
- **Der Plattenabstand soll aus dem Verbinder kommen**, nicht aus Distanzhülsen oder
  abgelängten Pins: Stapelverbinder gibt es in gestuften Steckhöhen. Gesucht ist ein
  Teil für gesteckt **10 mm — in beiden Spalten gleich**. Festlegung vom
  16.08.2026: Mid↔Top war mit 8–10 mm angesetzt, aber ein einziger Abstand
  heißt **ein einziges Bauteil auf allen drei Boards**, und genau das erlaubt
  es, den Stapel direkt zusammenzustecken. Den einen zusätzlichen Millimeter
  trägt das freie Tiefenbudget mühelos.
  **Achtung:** In den Layouts sitzt derzeit auf *allen drei* Boards dieselbe Buchse
  (`PinSocket_2x20_P1.27mm_Vertical`) — ein Platzhalter für die Mechanik, kein
  steckbares Paar. Punkt 23 in [`06-open-decisions.md`](06-open-decisions.md).

## 2. Strombelastbarkeit der Stackpins

Steckverbinder im 1,27-mm-Raster liegen typisch bei **≈ 1 A pro Kontakt**, bei mehreren
benachbart stromführenden Kontakten weniger. Die Zielgröße von 3 A für `5V_SYS` lässt
sich daher **nicht** über einen Pin führen.

| Rail | Zielstrom | Pins | Bemerkung |
|---|---|---|---|
| `5V_SYS` | bis 3 A | **4** | plus mindestens gleiche Anzahl GND als Rückpfad |
| `3V3_SYS` | bis 1,5 A | **2** | |
| `6V2_STAR` | 0,08 A real | 1 | mit eigenem `GND_STAR` |
| `GND` | Summe | **12** | verteilt, auch als Schirmung zwischen Signalen |

Vor dem Footprint-Freeze ist das Datenblatt des gewählten Verbinders gegen diese Tabelle
zu prüfen. Reicht die Belastbarkeit nicht, ist entweder die 3-A-Zielgröße für `5V_SYS`
zu senken (die realen 5-V-Verbraucher oberhalb des Bottom-Boards sind gering) oder ein
gröberes Raster zu wählen.

## 3. J_STK_A – Power und Motor (2×20, 1,27 mm)

**Version 0.3 — alle drei Generatoren importieren `tools/stack_pinout.py`; diese
Tabellen sind daraus erzeugt.** Damit können die Boards nicht auseinanderlaufen.

Konvention: ungerade Pins Reihe A, gerade Reihe B; Pin *n* und *n+1* liegen
nebeneinander. Pin 1 auf allen drei Boards gleich orientiert.

| Pin | Signal | Pin | Signal |
|---:|---|---:|---|
| 1 | `PGND` | 2 | `BTN2` |
| 3 | `5V_SYS` | 4 | `5V_SYS` |
| 5 | `5V_SYS` | 6 | `5V_SYS` |
| 7 | `PGND` | 8 | `PGND` |
| 9 | `3V3_SYS` | 10 | `3V3_SYS` |
| 11 | `PGND` | 12 | `PGND` |
| 13 | `6V2_STAR_F` | 14 | `PGND` |
| 15 | `PGND` | 16 | `M1_INA` |
| 17 | `M1_INB` | 18 | `USB_VBUS` |
| 19 | `PGND` | 20 | `M2_INA` |
| 21 | `PGND` | 22 | `M2_INB` |
| 23 | `STAR_EN` | 24 | `RSV_A2` |
| 25 | `PGND` | 26 | `I_SENSE1` |
| 27 | `AGND` | 28 | `I_SENSE2` |
| 29 | `AGND` | 30 | `HW_TRIP1` |
| 31 | `HW_TRIP2` | 32 | `TRIP_RST` |
| 33 | `RELAY_CTL` | 34 | `RSV_A3` |
| 35 | `RSV_A4` | 36 | `RSV_A5` |
| 37 | `RSV_A6` | 38 | `PGND` |
| 39 | `PGND` | 40 | `BTN3` |

Änderungen gegenüber v0.1:

- **`Mx_PWM`/`Mx_DIR` → `Mx_INA`/`Mx_INB`.** Je ein PWM-Ausgang pro Brückenzweig;
  spart Richtungslogik. `Mx_EN`/`Mx_FAULT` entfallen — `~SD` gehört dem Hardware-Trip.
- **`USB_VBUS` neu** (Pin 18). Beim Programmieren speist USB über das ORing auf dem
  Bottom-Board die Logik; die Datenleitungen bleiben wie bisher auf dem Top-Board.
- `RELAY_CTL` und `TRIP_RST` bleiben, `HW_TRIP1/2` kommen jetzt direkt vom Latch.

## 4. J_STK_B – UI und Kommunikation (2×20, 1,27 mm)

**Version 0.3.** Pins 15/16 führen beide `RS485_DIR` — DE und /RE des MAX3485 sind
auf dem Mid-Board zusammengelegt (Standard-Halbduplex, ein GPIO).

| Pin | Signal | Pin | Signal |
|---:|---|---:|---|
| 1 | `BTN1` | 2 | `EN_LOOP` |
| 3 | `3V3_SYS` | 4 | `3V3_SYS` |
| 5 | `I2C_SCL` | 6 | `PGND` |
| 7 | `I2C_SDA` | 8 | `PGND` |
| 9 | `PGND` | 10 | `I2C_INT` |
| 11 | `PGND` | 12 | `UART485_TX` |
| 13 | `PGND` | 14 | `UART485_RX` |
| 15 | `RS485_DIR` | 16 | `RS485_DIR` |
| 17 | `PGND` | 18 | `UART_AUX_TX` |
| 19 | `PGND` | 20 | `UART_AUX_RX` |
| 21 | `PRESENCE_INT` | 22 | `PGND` |
| 23 | `AUDIO_PWM` | 24 | `QSPI_CLK` |
| 25 | `PGND` | 26 | `PGND` |
| 27 | `PGND` | 28 | `PGND` |
| 29 | `PGND` | 30 | `PGND` |
| 31 | `QSPI_D0` | 32 | `QSPI_D1` |
| 33 | `PGND` | 34 | `QSPI_D2` |
| 35 | `QSPI_D3` | 36 | `DISP_CS` |
| 37 | `DISP_RST` | 38 | `DISP_BL` |
| 39 | `BTN4` | 40 | `PGND` |

- `QSPI_CLK` und `QSPI_D0–D3` laufen mit 40 MHz. Sie liegen bewusst gebündelt und
  bekommen im Layout gleiche Länge und durchgehende Massereferenz.
- `DISP_BL` ist die PWM für die Hintergrundbeleuchtung (LCD, kein AMOLED).
- Zwei Reservepins sind entfallen; ohne Reserve steht der Verbinder nicht da, aber
  eng ist es.

## 4b. Version 0.4 – Umbenennung nach dem Sensorwechsel

Der Radar ist durch einen **ToF-Sensor VL53L1X auf dem Top-Board** ersetzt
(Begründung: [`09-display-and-mcu.md`](09-display-and-mcu.md), Abschnitt 5).
Die Pinlage bleibt unverändert, nur die Namen sind jetzt ehrlich:

| Pin | v0.3 | v0.4 | Funktion |
|---:|---|---|---|
| `J_STK_B` 18 | `UART_RADAR_TX` | `UART_AUX_TX` | Reserve-UART auf J7 (unbestückt) |
| `J_STK_B` 20 | `UART_RADAR_RX` | `UART_AUX_RX` | Reserve-UART auf J7 (unbestückt) |
| `J_STK_B` 21 | `RADAR_INT` | `PRESENCE_INT` | GPIO1 des VL53L1X, geht auf PCF8574 P4 |

Neu belegt sind zwei bisher freie Expanderpins — **nicht** am Stackverbinder,
sondern nur auf dem Mid-Board:

| PCF8575 | Signal | Funktion |
|---|---|---|
| P5 | `RELAY_CTL` | PhotoMOS zur Dunstabzugshaube (LOW = geschlossen) |
| P6 | `REED1_IN` | Verschlusskontakt Fenster 1 |
| P7 | `REED2_IN` | Verschlusskontakt Fenster 2 |
| P10 (ESPHome 8) | `SAB1_IN` | **Sabotagekontakt Fenster 1** |
| P11 (ESPHome 9) | `SAB2_IN` | **Sabotagekontakt Fenster 2** |
| P12–P17 | — | Reserve |

Seit dem 16.08.2026 ist es ein **PCF8575** (16 Bit) statt des PCF8574: Mit vier
Reed-Kontakten reichten acht Portpins nicht mehr. Gleiche Adresse, gleicher
Treiber, ein Bauteil statt zwei.

## 5. Prüfliste vor dem Footprint-Freeze

- [ ] Stromrating des gewählten Verbinders gegen Abschnitt 2 geprüft
- [ ] Stapelhöhe des gewählten Teils ist **10 mm**, identisch in beiden Spalten
- [ ] Durchsteckbar: dasselbe Teil auf allen drei Boards, keine Buchse/Stecker-Zuordnung nötig
- [ ] Pin 1 auf allen drei Boards identisch orientiert
- [ ] Verpolungssicherheit: mechanisch unmöglich, A und B zu vertauschen
- [ ] Verfügbarkeit und Second Source geprüft

## 6. Änderungsverlauf

| Version | Änderung |
|---|---|
| **0.7** | **B2 wird `EN_LOOP` — der Hauptschalter.** Der Gate-Pulldown des Verpolschutz-FETs läuft als Schleife durch den Stapel: Q1-Gate → R1 → B2 → SW5 auf Top → PGND. Ohne Top-Board oder mit SW5 aus sperrt Q1, nichts hinter ihm bekommt 24 V. Vorher stand nach dem Verschrauben von Bottom und Mid sofort Spannung auf allem |
| 0.1 | Erster ausgearbeiteter Vorschlag aus der Projektzusammenfassung |
| **0.2** | **Aus dem Bottom-Schaltplan erzeugt.** `INA`/`INB` statt `PWM`/`DIR`, QSPI-Bus für das Display, `USB_VBUS` ergänzt |
| **0.5** | **Tasten und I2C auf die Außenreihe**, Tasten auf beide Verbinder verteilt. Anlass: Auf Top blieben mit drei verschiedenen Anläufen dieselben elf Netze offen |
| **0.4** | USB-C wandert auf das Mid-Board (Bauhöhe), `USB_DP`/`USB_DN` verlassen den Stack |
| **0.3** | **Gemeinsame Quelle `tools/stack_pinout.py`** für alle drei Boards. `USB_DP`/`USB_DN` durch den Stack (nativer USB), `STAR_EN` neu (Sternstecker sitzt auf TOP, der frühere J4 auf Bottom war ein Fehler), `RS485_DE`+`RE` → `RS485_DIR` |

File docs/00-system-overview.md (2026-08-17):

# 00 – Systemübersicht

## 1. Zielsystem

Stackbares PCB-System aus drei gestapelten Leiterplatten in einer massiven
Schalter-Unterputzdose mit 61 mm Tiefe.

- **Bottom und Mid: rund, Ø 52,0 mm** — sie sitzen in der Dose
- **Top: quadratisch, 47 × 47 mm mit R 4** — es sitzt **vor** der Dose im
  Adapter, weil die Druckkreuze der Zentralscheibe auf r = 26,9 liegen und ein
  Kreis dort nicht hinreicht ([`04-mechanical.md`](04-mechanical.md) 1d/1e)
- Bevorzugte Leiterplattendicke: **1,0 mm**
- Die drei Ebenen trennen Benutzeroberfläche/Sensorik, Logik/Kommunikation und
  Leistungselektronik/Motorsteuerung.

## 2. Externe Versorgung und Verbraucher

| Verbraucher | Spannung | Leistung | Strom | Anmerkung |
|---|---|---|---|---|
| Klappladenmotor 1 | 24 V DC ±10 % | max. 41 W (24 V an 14 Ω) | Dauer ≈ 0,3–1,0 A, **Blockierstrom 1,7 A gemessen** | 2 Adern, Umpolung, keine Elektronik |
| Klappladenmotor 2 | 24 V DC ±10 % | max. 41 W (24 V an 14 Ω) | Dauer ≈ 0,3–1,0 A, **Blockierstrom 1,7 A gemessen** | 2 Adern, Umpolung, keine Elektronik |
| Weihnachtsstern | 6,0–6,5 V | 0,5 W | ≈ 80 mA | nur im 24-V-Normalbetrieb |

Antrieb: Drehflügelmotor für Fensterläden, 25 Nm bei 1,9 U/min, Fahrzeit **18 s**
(≈ 205° Schwenk), −20…+60 °C, bis 50 kg je Flügel.

Die mechanische Abtriebsleistung beträgt nur ≈ 5 W, der Laufstrom entsprechend
≈ 0,3–1,0 A. **Der Motor hat keine eigene Elektronik** — die Hinderniserkennung ist
Aufgabe dieses Geräts.

Den Blockierstrom begrenzt allein der Ankerwiderstand, und der ist seit dem
17.08.2026 gemessen: **14 Ω, also 1,7 A**. Die 100 W auf dem Typenschild sind
demnach die Netzteilempfehlung der Anlage — 24 V an 14 Ω ergeben höchstens 41 W,
mehr kann der Motor gar nicht aufnehmen. Herleitung und Messprotokoll:
[`11-motor-data.md`](11-motor-data.md).

**Externe Verkabelung:** `24V_IN+` und `24V_IN−` kommen herein. Je Motor gehen zwei
Leitungen heraus: `M1_A`/`M1_B` und `M2_A`/`M2_B`. Insgesamt sechs Leistungsadern am
unteren Anschluss.

**USB-C** wird ausschließlich für Programmierung/Debug und ggf. Versorgung der Logik
während der Programmierung genutzt. Der Stern erhält einen **separaten
Frontanschluss** — eine 2,5-mm-Klinkenbuchse, Punkt 30 — und hängt nicht am USB-Port.

## 3. Peripherie (Stand der Schaltpläne)

| Funktion | Bauteil | Anzahl | Schnittstelle | Board |
|---|---|---|---|---|
| Temperatur + Feuchte | SHT40-AD1B, 0x44 | 1 | I2C | TOP |
| Runddisplay 360 × 360 | ST77916, 1,46" | 1 | QSPI + CS/RST/BL | TOP |
| Bedientaster | 8 SMD-Taster, je 2 parallel | 4 Tasten | GPIO | TOP |
| Präsenz / Durchstieg | VL53L1X (ToF) | 1 | I2C + INT | TOP |
| Stern-Ausgang 6,2 V | P-FET + PTC, 2,5-mm-Klinke | 1 | 2-polig | TOP (Front) |
| USB-C | nativer USB des S3, ESD USBLC6 | 1 | D+/D− durch den Stack | TOP |
| MCU | ESP32-S3-WROOM-1-N16R8 | 1 | — | MID |
| RS-485 | MAX3485 + Fail-Safe-Bias, JST-XH | 1 | UART + DIR | MID |
| GPIO-Expander | PCF8574, 0x20 | 1 | I2C | MID |
| Piezo | passiv + Treiberstufe | 1 | PWM (`rtttl`) | MID |
| Meldekontakt Haube | PhotoMOS AQY282GS (SELV) | 1 | Expander P5 | MID |
| Verschlusskontakte | Reed, Pull-up + RC + ESD, JST-SH | 2 | Expander P6/P7 | MID |
| Motorendstufe / H-Brücke | 2 × IR2104 + 4 N-FET je Kanal | 2 | 2 × PWM (INA/INB) | BOTTOM |
| Strommessung je Motor | 5 mΩ Inline-Shunt + INA240A2 | 2 | analog | BOTTOM |
| Hardware-Überstromabschaltung | TLV3702 + 74AUP1G74 auf `~SD` | 2 | Expander P0–P2 | BOTTOM |

Der frühere **Mini-Radar** ist durch den ToF-Sensor ersetzt (Punkt 17), das
frühere **Mini-Relais** durch den PhotoMOS (Punkt 21), der **USB-UART-Baustein**
entfällt durch den nativen USB des ESP32-S3 (Punkt 24). Was davon in Firmware
tatsächlich ausgewertet wird, steht in
[`13-funktionsstatus.md`](13-funktionsstatus.md).

RS-485 ist die **primäre** Kommunikation. WLAN am ESP32 ist sekundär/nice-to-have.

> **Die Feldperipherie ist gegenüber dem Ursprungsentwurf unvollständig.** Der
> Vorgängerentwurf führte je Laden **zwei** Kontakte (Verschluss *und* Sabotage) und
> einen externen Temperaturfühler an zwei 10-poligen Schraubklemmen. Beides fehlt hier.
> Auswertung und Belege: [`12-legacy-socos.md`](12-legacy-socos.md), Entscheidung
> offen als Punkte 34 und 35 in [`06-open-decisions.md`](06-open-decisions.md).

## 4. Board-Aufteilung

### TOP – Front / UI
Runddisplay ST77916 über QSPI, vier Sicheltasten (8 Taster), SHT4x, VL53L1X
hinter dem oberen Steg (12 Uhr), Klinkenbuchse für den Stern im unteren Steg
(6 Uhr), USB-C am Rand oben links neben dem ToF.

### MID – Logic
ESP32-S3, RS-485-Transceiver, GPIO-Expander, Piezo, PhotoMOS für den
Haubenkontakt, Feldstecker für die Verschlusskontakte.

### BOTTOM – Power & Motor
24-V-Eingangsschutz, zwei Motor-H-Bridges, Strommessung, hardwareseitige
Überstromabschaltung, DC/DC-Wandler, unterer Hochstrom-Steckverbinder.

## 5. Zentrale Designregel

Motor/24-V-Leistung unten, digitale Logik/Kommunikation in der Mitte, UI/Sensorik oben.
Hochstrom bleibt auf dem Bottom-Board. Stackverbinder transportieren nur Signale und
Kleinleistung.

## 6. Zuordnungshinweise / Prüfpunkte

Beide Punkte dieses Abschnitts sind inzwischen entschieden — sie bleiben als
Entscheidungsprotokoll stehen:

- ~~**Mini-Relais**~~ → **PhotoMOS AQY282GS auf dem Mid-Board** (Punkt 21). Potentialfrei,
  60 V / 0,8 A, kein Spulenstrom, keine Bauhöhe im Stapelspalt. **Die Freigabe gilt
  ausdrücklich nur für SELV.** Erwartet die Dunstabzugshaube 230 V, gehört das
  Schaltglied nicht in diese Dose — dann kippt die ganze Isolations- und
  Kriechstreckenbetrachtung und mit ihr die Board-Aufteilung.
- **ADC:** Die Strommessung hängt am **internen ADC des ESP32-S3** (`I_SENSE1/2` über
  `J_STK_A` 26/28). Ein externer ADC bleibt als Punkt 18 offen — er wird erst
  relevant, wenn die C++-Komponente zeigt, dass das PWM-synchrone Sampling mit dem
  internen ADC nicht ausreicht. Herleitung: [`02-motor-control.md`](02-motor-control.md),
  Grenzen: [`09-display-and-mcu.md`](09-display-and-mcu.md) Abschnitt 4.

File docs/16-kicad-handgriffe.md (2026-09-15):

# 16 – Die letzten Handgriffe in KiCad

Der Autorouter ist fertig, ein paar Verbindungen bleiben. Diese Seite ist die
Anleitung dafür — kurz, weil es wenig ist.

> **Warum das übrig bleibt.** Freerouting löst rund 98 % und meldet dann
> selbst, es komme nicht weiter. Was übrig bleibt, sind fast immer Pads, die
> zwischen anderen Bauteilen eingeklemmt sind. Von Hand ist das jeweils ein
> Zug mit der Maus.

## 1. Was zu tun ist

Öffne jedes Board einzeln, **nicht den Nutzen** — der entsteht danach neu aus
den Einzelboards.

```
hardware/top_ui/top_ui.kicad_pro
hardware/mid_logic/mid_logic.kicad_pro
hardware/bottom_power_motor/bottom_power_motor.kicad_pro
```

Die verbindliche Liste liefert immer **Inspect → Design Rules Checker**,
Häkchen bei „Report all errors for each track" aus, dann **Run DRC**. Unter
`unconnected_items` steht jede offene Verbindung mit Koordinate.

Dasselbe ohne KiCad zu öffnen: `python3 tools/handarbeit_liste.py` läuft die
DRC über alle drei Boards und druckt jede offene Verbindung mit Netz,
Endpunkten, Koordinaten und Luftlinie. Nach jedem Speichern erneut aufrufen —
die Liste schrumpft mit.

## 2. Offene Verbindungen ziehen

1. **Ansicht aufräumen:** `Ansicht → Ratsnest anzeigen` einschalten. Die dünnen
   weißen Linien sind genau die offenen Verbindungen.
2. **Lagen einblenden:** Alle vier Kupferlagen sichtbar lassen. Der Router hat
   `In1.Cu` und `In2.Cu` benutzt, dort ist meistens noch Platz.
3. **Bahn ziehen:** Taste **X**, auf das Pad klicken, zum Ziel ziehen.
   Mit **V** wechselt man mitten im Zug die Lage und setzt automatisch ein Via.
4. **Nicht die Breite ändern.** Die Netzklassen stehen im Projekt; KiCad nimmt
   automatisch die richtige. Nur bei den Leistungsnetzen (`24V_IN`, `M1_A`,
   `M1_B`, `M2_A`, `M2_B`) darauf achten, dass die Bahn nicht schmaler wird
   als die vorhandene.

**Stand vom 15.09.2026** (nach dem Aufräumen, siehe Abschnitt 3):

| Board | offen | wo |
|---|---|---|
| **Top** | 5 | `3V3_SYS`, `I2C_SDA`, `I2C_SCL` — alle drei zu U2 an der Unterkante, 9–12 mm, als Bündel ziehen; `6V2_STAR_F` (Q2 Pad 2 → Bahn auf B.Cu, 5,4 mm); 1× `PGND` an J5 Pad 2 (0,3 mm — Bahn auf B.Cu, Pad auf F.Cu, es fehlt nur das Via) |
| **Mid** | 15 | `3V3_SYS` (2×), `RELAY_CTL` (zwei lose In1.Cu-Enden an der USB-Bohrung, außen herum führen), `USB_CC2` (R19 → J7 Pad B5, 7,5 mm), 11× `PGND` — davon 2 Zone-Inseln ohne Koordinate |
| **Bottom** | 26 | `24V_PROT` (2×, U2/U4 Pad 2 → Bahn bei (−4,05/−17,59) — Leistungspfad, breit), `3V3_SYS` (3×, UM1_FF/UM2_FF Pad 8, UM2_GB Pad 5), 21× `PGND` — davon 11 Zone-Inseln ohne Koordinate |

Fast alle `PGND`-Einträge mit Koordinate zeigen dasselbe Muster: Pad auf der
einen Lage, Bahn oder Pad auf der anderen, 1–4 mm auseinander — ein Via mit
kurzem Stich. Die Zone-Inseln haben in der DRC keine brauchbare Koordinate;
sie findet man nur über das Ratsnest nach **B**.

### `M1_ISNS` — inzwischen geroutet, die Lehre bleibt

Der Motorstrom-Messpfad von Motor 1 war auf Bottom eine Zeit lang mit
Absicht leer und ist inzwischen verdrahtet. Die Geschichte bleibt hier
stehen, weil die `3V3_SYS`-Reste bei UM1_FF/UM2_FF in derselben Ecke liegen
und dort dieselbe Regel gilt: Der Router hatte `M1_ISNS` geroutet, und zwar
falsch.

Freerouting hat `M1_ISNS` auf F.Cu direkt an `V_TRIP_LO` gepresst, auf
engstem Raum um (1,2–1,7 / 5,3–6,2). Ergebnis waren vier Kurzschlüsse, eine
Kreuzung und ein Abstandsfehler. Einzeln herausgelöste Segmente haben das
Problem nur verschoben: Nach jedem Eingriff meldete die DRC dieselben zwei
Netze an der nächsten Stelle.

Sachlich ist die Paarung ohnehin die schlechtestmögliche. `M1_ISNS` ist das
analoge Messsignal des Motorstroms, `V_TRIP_LO` die Vergleichsschwelle, gegen
die es ausgewertet wird. Koppeln die beiden, verschiebt sich die
Auslöseschwelle mit dem gemessenen Strom — die Hinderniserkennung würde sich
selbst verstimmen, und zwar ohne dass eine DRC das je bemerkt.

**Wer in dieser Ecke Hand anlegt, hält deshalb ein:**

- `M1_ISNS` mit **spürbarem Abstand** zu `V_TRIP_LO` führen, gern über eine
  andere Lage. Nicht parallel über längere Strecken.
- Zwischen beiden möglichst Massefläche stehen lassen.
- Kurz halten: vom Shunt `R_M1_SH` zum Messverstärker, nicht quer über das
  Board.

Bei Motor 2 hat der Router dieselbe Ecke ohne Fehler gelöst — `M2_ISNS` zeigt
also, dass dort ein Weg existiert. Als Vorbild taugt es aber nur für die
Wegführung, nicht für die Länge: Die Bahn ist 70,9 mm lang und läuft damit
weiter über das Board, als einem Messsignal guttut. Wer ohnehin gerade von
Hand routet, darf auch `M2_ISNS` gern kürzen.
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

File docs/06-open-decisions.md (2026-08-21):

# 06 – Offene Entscheidungen

Legende Priorität: **P0** blockiert den nächsten Arbeitsschritt · **P1** vor
Layout-Freeze nötig · **P2** vor Fertigungsfreigabe nötig.

Welche Funktionen diese Punkte blockieren, zeigt
[`13-funktionsstatus.md`](13-funktionsstatus.md).

## Kritischer Pfad

| # | Prio | Entscheidung | Abhängig davon |
|---|---|---|---|
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

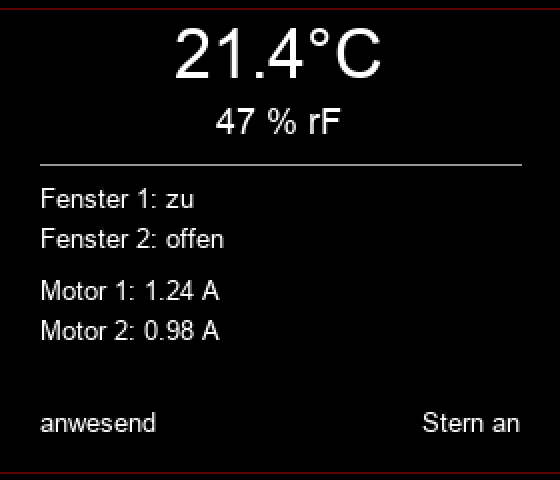
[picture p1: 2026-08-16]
mechanical/export/display_fahrt.png

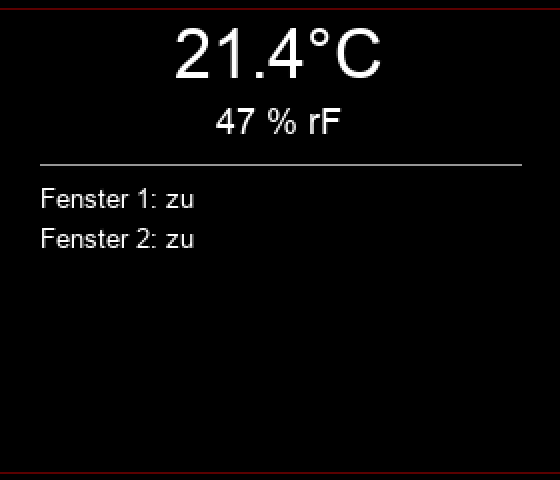
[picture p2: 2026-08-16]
mechanical/export/display_normal.png

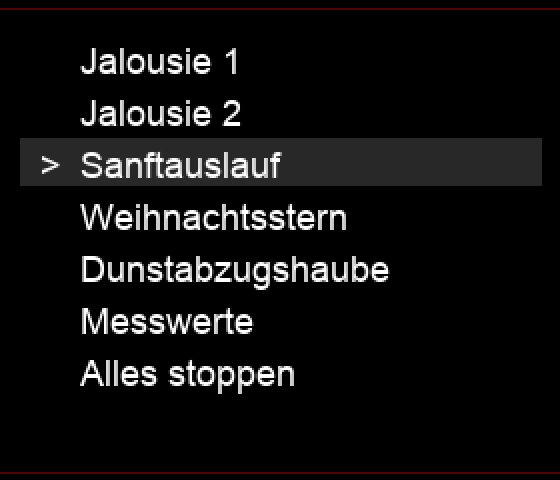
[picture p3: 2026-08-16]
mechanical/export/display_menue.png

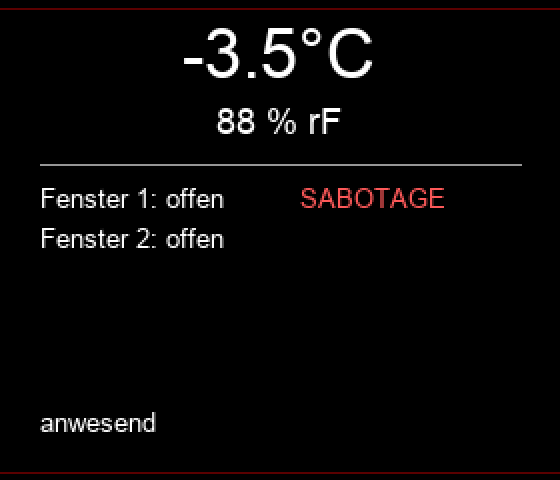
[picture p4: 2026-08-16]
mechanical/export/display_alarm.png

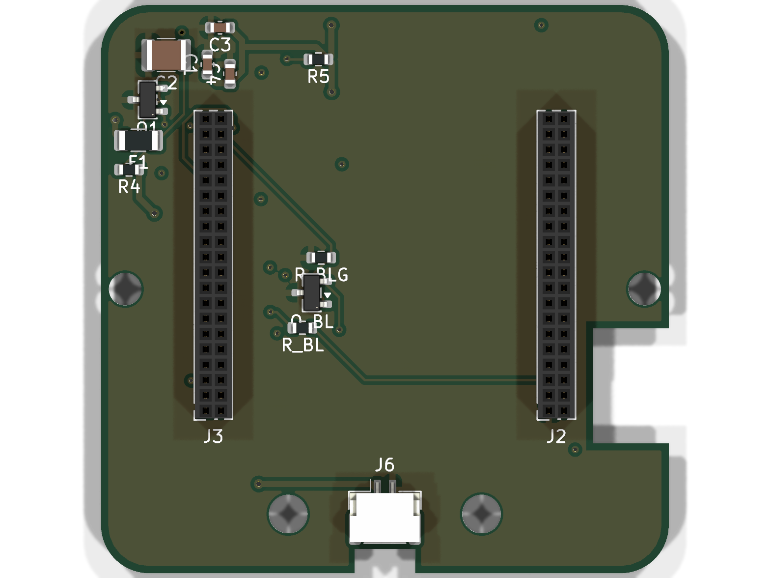
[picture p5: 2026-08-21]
docs/renders/top_ui_bottom.png

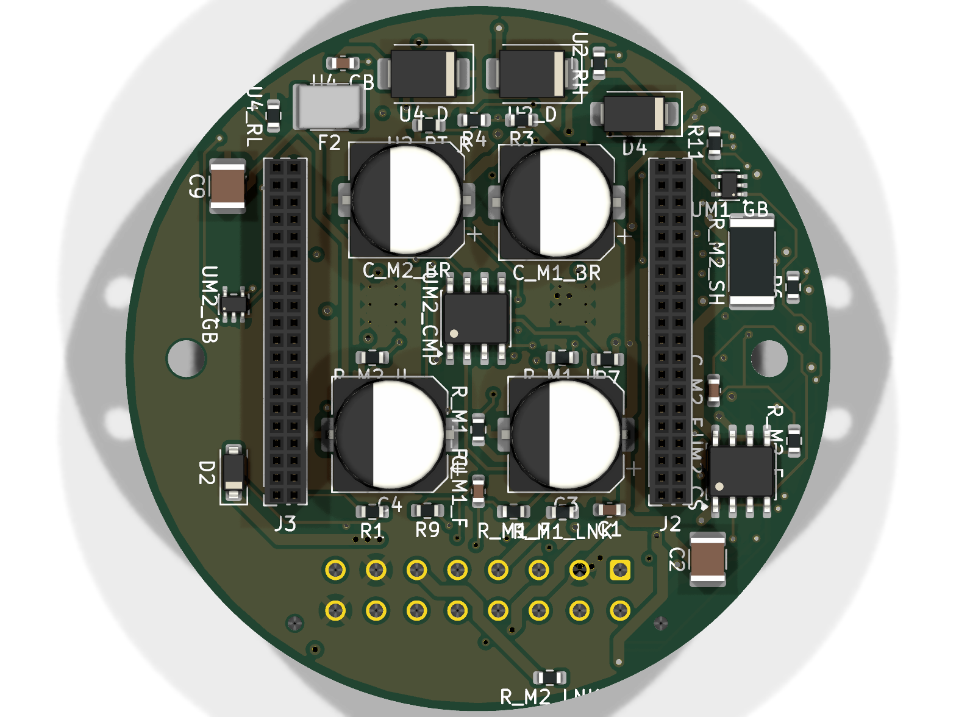
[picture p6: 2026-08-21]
docs/renders/bottom_power_motor_bottom.png

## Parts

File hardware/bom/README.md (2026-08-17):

# Stückliste und Fertigung

> **Für das Bottom-Board gibt es jetzt eine erzeugte Stückliste:**
> [`../bottom_power_motor/bom_bottom.csv`](../bottom_power_motor/bom_bottom.csv) —
> 103 Bauteile, 52 Positionen, aus derselben Quelle wie der Schaltplan erzeugt und
> damit garantiert konsistent. Was dort noch fehlt, sind Hersteller-Teilenummern für
> die Leistungsbauteile.
>
> **Status ehrlich benannt:** Der Rest hier ist eine **Auswahl- und Beschaffungsliste**,
> keine fertigungsfähige BOM. Eine bestellbare BOM entsteht erst aus dem fertigen Schaltplan
> — Referenzbezeichner (`R1`, `U3`, …), Werte und Footprints kommen aus KiCad. Ohne
> Layout gibt es auch keine Positionsdatei (CPL) und keine Gerber. Was noch fehlt,
> steht unten unter „Weg zur Bestellung".

Alle Teile sind Empfehlungen mit Begründung. Preise und Lagerbestand sind bei der
Bestellung zu prüfen — beides ändert sich laufend.

## 1. Kernkomponenten

### MCU und Anzeige

| Funktion | Empfehlung | Warum |
|---|---|---|
| MCU | **ESP32-S3-WROOM-1-N16R8** | PSRAM für den Framebuffer (466² × 16 bit ≈ 434 kB), **nativer USB** spart den USB-UART-Baustein, 16 MB Flash für OTA |
| Display | **1,69" LCD rechteckig, ST7789, 240×280, quer** | Das Fenster der Zentralscheibe (32,70 × 27,00) gibt die Form vor; die aktive Fläche 32,63 × 27,97 füllt es randlos. ESPHome-nativ. **Modulaußenmaß vor dem Layout messen** (Punkt 15c) |
| Taster | **4 ×** SMD-Kurzhubtaster, niedrig (z. B. Panasonic EVQP2 3,9×2,9 mm) | einer je Ecke, exakt unter den Druckkreuzen der Zentralscheibe bei (±18 · ±20). Bauhöhe ≤ 2,0 mm — sie steht in der Tiefenkette, siehe `docs/04` 1e |
| GPIO-Expander | **PCF8575** (16 Bit, SSOP-24) | Acht Portpins reichten mit vier Reed-Kontakten nicht mehr. Gleiche Adresse, gleicher ESPHome-Treiber (`pcf8574` mit `pcf8575: true`) |

Begründung der Displaywahl im Detail: [`../../docs/09-display-and-mcu.md`](../../docs/09-display-and-mcu.md).

### Leistung

| Funktion | Kandidat | Kernkriterium bei der Auswahl |
|---|---|---|
| Gate-Treiber ×4 | **IR2104** (Halbbrücke, `~SD`-Eingang) | zwei je Motorkanal; `~SD` ist der Eingriffspunkt des Hardware-Trips |
| Shunt ×2 | **5 mΩ**, 1 W, 4-Terminal (Kelvin), 2512 | 4-Terminal ist Pflicht. 5 statt 1 mΩ seit der Blockierstrommessung (1,7 A): ergibt mit INA240-Verstärkung 50 genau 0,25 V/A und ±6,6 A Messbereich |
| Current-Sense-Amp ×2 | **INA240A2D** | bidirektional, hoher Gleichtaktbereich, PWM-tauglich |
| Comparator + Latch ×2 | **TLV3702** (Fenster) + **74AUP1G74** | wirkt ohne Firmware. **Kein LM393** — dessen Gleichtakt-Eingangsbereich reicht bei 3,3 V nur bis 1,8 V, die obere Trip-Schwelle liegt bei 2,752 V. Pflicht sind **Rail-to-Rail-Eingang** und **Open-Drain-Ausgang** (das Wire-OR hängt daran), SOIC-8 im Standard-Pinout. Vor der Bestellung gegen das Datenblatt prüfen — siehe Punkt 57 |
| Buck 24→5 V | **TPS54360DDA** | strikt nach Referenzlayout aufbauen |
| Buck 5→3,3 V | **TLV62569DBV** | |
| Buck 24→6,2 V | **TPS54360DDA** (gleiches Teil wie oben) | für den Weihnachtsstern |
| USB-ORing | 2× Schottky (D4/D5) | einfach, kein Rückstrom; bei hoher 5-V-Last durch Ideal-Diode ersetzen |

> **Einzige offene Leistungsposition: der N-Kanal-MOSFET** (8 Stück). Er bestimmt,
> welchen Blockierstrom die Endstufe übersteht, und genau der ist nicht gemessen.
> Vorgabe bis dahin: 40 V, ≥ 60 A Puls, PowerPAK SO-8, Rds(on) < 5 mΩ. Die diskrete
> Topologie wurde bewusst gewählt, damit diese eine Entscheidung nachträglich
> änderbar bleibt.

### Sensorik und Kommunikation

| Funktion | Empfehlung | Warum |
|---|---|---|
| Temperatur + Feuchte | **SHT4x** (SHT40/41/45), I2C | ein Baustein für beides, spart Platz und eine I2C-Adresse; ESPHome `sht4x` |
| RS-485 | Transceiver mit **Fail-Safe-Bias**, 3,3 V | ohne Fail-Safe klappert der Bus im Leerlauf |
| Präsenz | **VL53L1X** (ToF), I2C + INT | ersetzt den früheren Radar — 4,9 × 2,5 mm passen hinter den Steg, ein 20-mm-Radarmodul nicht |
| Piezo | passiver Signalgeber | passiv, nicht aktiv — nur so funktioniert ESPHome `rtttl` |

### Steckverbinder

| Position | Kandidat | Prüfpunkt |
|---|---|---|
| Bottom, 6-polig | **Micro-Fit 3.0 2×3 reicht** | Pin 1/2 führen ≈ 4,1 A Spitze, nicht die früher angenommenen 9 A. Mini-Fit Jr. ist nicht mehr nötig — siehe [`../../docs/01-power-tree.md`](../../docs/01-power-tree.md) |
| Stern-Ausgang | **2,5-mm-Klinkenbuchse** an der Front | 80 mA, unkritisch; Bauhöhe max. 10,5 mm, Footprint noch Platzhalter (Punkt 30) |
| Stack ×2 | 2×20, 1,27 mm | **≈ 1 A pro Kontakt** — `5V_SYS` braucht mehrere Pins |

## 2. Leiterplatten

| | BOTTOM | MID | TOP |
|---|---|---|---|
| Umriss | Ø 52,0 mm | Ø 52,0 mm | **47 × 47 mm, R 4** |
| Dicke | 1,0 mm | 1,0 mm | 1,0 mm |
| Lagen | 2 oder 4 | 4 | 2 |
| Kupfer | **2 oz prüfen** | 1 oz | 1 oz |
| Oberfläche | ENIG empfohlen | ENIG | ENIG |

ENIG statt HASL, weil die 1,27-mm-Stackverbinder und das ESP32-Modul feine Raster
haben und HASL dort ungleichmäßig aufträgt.

## 3. Weg zur Bestellung

Was noch fehlt, in der Reihenfolge, in der es entsteht:

1. **Schaltplan je Board** — liefert Referenzbezeichner und Werte.
2. **Bauteilauswahl abschließen** — setzt die Motorstrommessung voraus.
3. **Layout und Routing** — liefert die Positionsdatei.
4. **DRC und Stromtragfähigkeit prüfen** — siehe [`../../docs/05-manufacturing.md`](../../docs/05-manufacturing.md).
5. **Export** aus KiCad:
   ```
   kicad-cli pcb export gerbers  -o production/gerber <board>.kicad_pcb
   kicad-cli pcb export drill    -o production/gerber <board>.kicad_pcb
   kicad-cli pcb export pos      -o production/cpl.csv --format csv --units mm <board>.kicad_pcb
   kicad-cli sch export bom      -o production/bom.csv <board>.kicad_sch
   ```
6. **BOM auf das Format des Fertigers mappen** — bei JLCPCB sind die Spalten
   `Comment`, `Designator`, `Footprint`, `LCSC Part #`.

### Fertigerempfehlung

| Anbieter | Wofür | Anmerkung |
|---|---|---|
| **JLCPCB** | Prototyp mit Bestückung | günstigste Bestückung, aber Teile müssen aus dem LCSC-Katalog kommen; runde Boards und 1,0 mm sind Standard |
| **Aisler** | EU, kleine Serie | Versand aus DE/NL, keine Zollthemen, teurer |
| **PCBWay** | Sonderwünsche | 2 oz, ungewöhnliche Stackups, mehr Handarbeit möglich |

Für dieses Projekt: **Bottom-Board bei einem Anbieter mit 2-oz-Option**, Mid und Top
unkritisch. Die Bestückung der Leistungsbauteile von Hand nachzuarbeiten ist bei
Prototypen oft günstiger, als sie durch den Bestückungsservice zu treiben.

> Bei JLCPCB-Bestückung: die Bauteilauswahl wird faktisch vom LCSC-Katalog
> vorgegeben. Wer dort bestücken lassen will, sollte die Verfügbarkeit **vor** dem
> Schaltplan prüfen, nicht danach — sonst wird das halbe Design nochmal angefasst.

## 6. Bestellung: Fertiger und Bestückung

**Stand 16.08.2026: bestellbar ist noch nichts.** Was zuerst erledigt sein muss,
steht in [`../../docs/13-funktionsstatus.md`](../../docs/13-funktionsstatus.md);
die harten Blocker sind der ungemessene Blockierstrom (damit der N-FET,
Punkt 8), zwei Platzhalter-Footprints (Klinke Punkt 30, Displaystiftleiste
Punkt 15c), der Stapelverbinder ohne Teilenummer (Punkt 23) und das fehlende
Routing von Mid und Bottom.

### Was der Nutzen für eine Bestückung noch braucht

Der Nutzen ist für die **Leiterplattenfertigung** ausgelegt, nicht für die
Bestückung. Drei Dinge fehlen und sind vor der PCBA-Bestellung zu ergänzen
(Punkt 52):

| fehlt | warum |
|---|---|
| **Passermarken** (Fiducials) | Der Bestücker richtet den Nutzen daran aus. Üblich sind drei global, diagonal versetzt, plus lokale Marken an feinpoligen Bauteilen — hier ESP32-Modul, PCF8575 (0,65 mm) und USB-C |
| **Breitere Ränder** | 4,0 mm reichen zum Fräsen, nicht zum Transport durch die Bestückungslinie. Üblich sind 5–10 mm an zwei gegenüberliegenden Seiten |
| **Werkzeugbohrungen** | zwei bis drei unbelegte Ø-3-mm-Löcher im Rand |

### Anbieterwahl

Für **5 Stück** und für **25 Stück** liegen beide noch im Prototypentarif —
die Losgröße ist nicht das, was die Wahl entscheidet. Entscheidend sind drei
andere Dinge:

1. **Bauteilabdeckung.** Der günstigste Tarif bei JLCPCB verlangt, dass die
   *gesamte* Stückliste aus dem LCSC-Lager kommt. Was dort fehlt, muss
   beigestellt werden — und Beistellung ist bei Kleinserien der teuerste Teil.
   **Konsequenz für die noch offene Bauteilauswahl: Wo es die Wahl gibt, ein
   LCSC-gelistetes Teil nehmen.** Die USB-C-Buchse ist mit C2843970 bereits so
   gewählt; beim N-FET (Punkt 8) ist das jetzt zu berücksichtigen.
2. **Doppelseitige Bestückung plus Durchsteckteile.** Das Mid-Board trägt
   Bauteile auf beiden Seiten (Expander und Feldstecker hinten), dazu kommen
   THT-Teile: Stapelverbinder, Leistungsstecker, Klinke. Beides zusammen
   schließt die billigsten Stufen aus.
3. **Wohin die Rechnung zeigt.** Aus der EU (AISLER, Eurocircuits) entfallen
   Zoll, Wartezeit und Einfuhrumsatzsteuer, und man bekommt brauchbares
   DFM-Feedback; aus China (JLCPCB, PCBWay) ist der reine Preis in dieser
   Stückzahl deutlich niedriger.

**Ein Mittelweg, der für dieses Projekt gut passt:** Leiterplatten und
**SMD-Bestückung** fertigen lassen, die **Durchsteckteile selbst löten**. Das
sind genau die Teile, die schwer zu beschaffen sind (Micro-Fit, Stapelverbinder,
Klinke) — und die man beim Prototyp ohnehin noch tauschen will.

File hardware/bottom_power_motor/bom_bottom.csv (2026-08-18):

Menge | Designator | Wert | Footprint | Hinweis
6 | C1,C10,C_M1_CS,C_M2_CS,U2_CB,U4_CB | 100n | Capacitor_SMD:C_0603_1608Metric
1 | C2 | 10u | Capacitor_SMD:C_1210_3225Metric
2 | C3,C4 | 220u/35V Polymer | Capacitor_SMD:CP_Elec_8x6.5
4 | C7,C8,C9,U4_CO | 22u | Capacitor_SMD:C_1210_3225Metric
2 | C_M1_BR,C_M2_BR | 100u 50V | Capacitor_SMD:C_1210_3225Metric | Bulk je Bruecke. Das Original kommt mit 47 uF fuer BEIDE Motoren aus (docs/14) - 100 uF je Kanal ist reichlich
2 | C_M1_F,C_M2_F | 1n | Capacitor_SMD:C_0603_1608Metric
1 | D1 | SMBJ30A | Diode_SMD:D_SMB
1 | D2 | 12V | Diode_SMD:D_SOD-123
2 | D4,D5 | 40V 3A | Diode_SMD:D_SMA | Vf klein waehlen - Verlust siehe docs/01
1 | F1 | 15A traege | Fuse:Fuse_Littelfuse-NANO2-451_453 | SMD NANO2, messabhaengig - siehe docs/11
1 | F2 | 0.5A | Fuse:Fuse_1812_4532Metric
1 | J1 | Feld 16p | Connector_Molex:Molex_Micro-Fit_3.0_43045-1612_2x08_P3.00mm_Vertical | Molex 43045-1612, 2x8, stehend - EIN Stecker fuer alles, SELV
1 | J2 | J_STK_A | Connector_PinSocket_1.27mm:PinSocket_2x20_P1.27mm_Vertical
1 | J3 | J_STK_B | Connector_PinSocket_1.27mm:PinSocket_2x20_P1.27mm_Vertical
1 | L1 | 2u2 | Inductor_SMD:L_Bourns_SRP5030T
1 | Q1 | P-FET 40V 30A | Package_SO:PowerPAK_SO-8_Single | z.B. SiR429DP; Pad-Zuordnung siehe PAD_MAP in gen_layouts
2 | R1,R10 | 100k | Resistor_SMD:R_0603_1608Metric
1 | R3 | 392k | Resistor_SMD:R_0603_1608Metric
1 | R4 | 88k7 | Resistor_SMD:R_0603_1608Metric
1 | R5 | 180k | Resistor_SMD:R_0603_1608Metric
1 | R6 | 40k2 | Resistor_SMD:R_0603_1608Metric
2 | R7,R9 | 10k0 | Resistor_SMD:R_0603_1608Metric | Trip-Schwelle 4,4 A
1 | R8 | 40k2 | Resistor_SMD:R_0603_1608Metric | Trip-Schwelle 4,4 A
1 | R11 | 1k | Resistor_SMD:R_0603_1608Metric | Reset vom I2C-Expander
1 | R12 | 0R | Resistor_SMD:R_0603_1608Metric | einziger Verbindungspunkt Signal- und Leistungsmasse
4 | R_M1_PU,R_M2_PU,U2_RC,U4_RC | 10k | Resistor_SMD:R_0603_1608Metric
2 | R_M1_IL,R_M2_IL | 33k0 | Resistor_SMD:R_0603_1608Metric | Strombegrenzung DRV8871 - Wert gegen Datenblatt pruefen
2 | R_M1_SH,R_M2_SH | 5m0 1W | Resistor_SMD:R_2512_6332Metric | 4-Terminal, Kelvin - Pflicht
2 | R_M1_LNK,R_M2_LNK | 0R | Resistor_SMD:R_0603_1608Metric | Bruecke, erlaubt spaeteres Auftrennen zur Messung
2 | R_M1_F,R_M2_F | 1k | Resistor_SMD:R_0603_1608Metric
2 | U2,U4 | TPS54360 | Package_SO:HSOP-8-1EP_3.9x4.9mm_P1.27mm_EP2.41x3.1mm
1 | U2_L | 10u | Inductor_SMD:L_Bourns_SRP7028A_7.3x6.6mm
2 | U2_D,U4_D | 60V 3A | Diode_SMD:D_SMB
1 | U2_RH | 53k6 | Resistor_SMD:R_0603_1608Metric
1 | U2_RL | 10k2 | Resistor_SMD:R_0603_1608Metric
2 | U2_RT_R,U4_RT_R | 100k | Resistor_SMD:R_0603_1608Metric | fsw ca. 500 kHz - gegen Datenblatt pruefen
2 | U2_CZ,U4_CZ | 3n3 | Capacitor_SMD:C_0603_1608Metric
1 | U2_CO | 47u | Capacitor_SMD:C_1210_3225Metric
1 | U3 | TLV62569 | Package_TO_SOT_SMD:SOT-23-5
1 | U4_L | 33u | Inductor_SMD:L_Bourns_SRP7028A_7.3x6.6mm
1 | U4_RH | 68k1 | Resistor_SMD:R_0603_1608Metric
1 | U4_RL | 10k0 | Resistor_SMD:R_0603_1608Metric
2 | UM1_BR,UM2_BR | DRV8871 | Package_SO:HSOP-8-1EP_3.9x4.9mm_P1.27mm_EP2.41x3.1mm_ThermalVias | 45 V, 3,6 A Spitze, Strombegrenzung ueber ILIM - Thermalpad an PGND anbinden
4 | UM1_GA,UM1_GB,UM2_GA,UM2_GB | 74AHC1G08 | Package_TO_SOT_SMD:SOT-353_SC-70-5
2 | UM1_CS,UM2_CS | INA240A2 | Package_SO:SOIC-8_3.9x4.9mm_P1.27mm | Pinbelegung gegen Datenblatt pruefen
2 | UM1_CMP,UM2_CMP | TLV3702 | Package_SO:SOIC-8_3.9x4.9mm_P1.27mm | Rail-to-Rail-Eingang + Open-Drain PFLICHT - kein LM393
2 | UM1_FF,UM2_FF | 74AUP1G74 | Package_TO_SOT_SMD:SOT-353_SC-70-5 | D-FF mit PRE und CLR

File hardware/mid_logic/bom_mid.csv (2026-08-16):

Menge | Designator | Wert | Footprint | Hinweis
1 | BZ1 | Piezo passiv SMD | Buzzer_Beeper:Buzzer_Murata_PKMCS0909E | Murata PKMCS0909E o.ae., 9 x 9 x 3 mm SMD - passiv, ein aktiver Summer kann keine rtttl-Melodien. SMD statt des frueheren THT-Typs (12 x 9,5): der blockierte beide Platinenseiten, und auf der Rueckseite fehlte danach der Platz fuer den 16-Bit-Expander
1 | C1 | 10u | Capacitor_SMD:C_0805_2012Metric
7 | C2,C5,C6,C7,C8,C9,C10 | 100n | Capacitor_SMD:C_0603_1608Metric
2 | C3,C4 | 1u | Capacitor_SMD:C_0603_1608Metric
1 | D1 | 40V | Diode_SMD:D_SOD-123
4 | D2,D3,D5,D6 | 5V6 | Diode_SMD:D_SOD-123 | ESD am Feldstecker
1 | D4 | 33V | Diode_SMD:D_SOD-123 | Klemmung am Haubenausgang
1 | J2 | J_STK_A | Connector_PinSocket_1.27mm:PinSocket_2x20_P1.27mm_Vertical
1 | J3 | J_STK_B | Connector_PinSocket_1.27mm:PinSocket_2x20_P1.27mm_Vertical
1 | J4 | RS485 A/B/GND | Connector_JST:JST_XH_B3B-XH-A_1x03_P2.50mm_Vertical | Kabel VOR dem Stapeln stecken - Zugaenglichkeit im Review pruefen
1 | J5 | Feld: 4 Reed | Connector_JST:JST_SH_BM06B-SRSS-TB_1x06-1MP_P1.00mm_Vertical | 1 REED1 2 SAB1 3 GND | 4 REED2 5 SAB2 6 GND
1 | J6 | Haubenkontakt | Connector_JST:JST_SH_BM02B-SRSS-TB_1x02-1MP_P1.00mm_Vertical | potentialfrei ueber den PhotoMOS - NUR SELV
1 | Q2 | BC847 | Package_TO_SOT_SMD:SOT-23
2 | R1,R2 | 10k | Resistor_SMD:R_0603_1608Metric
1 | R3 | 560R | Resistor_SMD:R_0603_1608Metric | Fail-Safe-Bias A
1 | R4 | 560R | Resistor_SMD:R_0603_1608Metric | Fail-Safe-Bias B
1 | R5 | 120R | Resistor_SMD:R_0603_1608Metric | DNP - nur bestuecken, wenn dieses Geraet am Busende sitzt
2 | R6,R7 | 4k7 | Resistor_SMD:R_0603_1608Metric
1 | R8 | 1k | Resistor_SMD:R_0603_1608Metric
1 | R9 | 10k | Resistor_SMD:R_0603_1608Metric | Pullup Reed 1
1 | R10 | 10k | Resistor_SMD:R_0603_1608Metric | Pullup Reed 2
1 | R11 | 1k | Resistor_SMD:R_0603_1608Metric | Serie Reed 1
1 | R12 | 1k | Resistor_SMD:R_0603_1608Metric | Serie Reed 2
1 | R13 | 330R | Resistor_SMD:R_0603_1608Metric | LED-Strom PhotoMOS, ca. 6 mA
1 | R14 | 10k | Resistor_SMD:R_0603_1608Metric | Pullup Reed 3
1 | R15 | 10k | Resistor_SMD:R_0603_1608Metric | Pullup Reed 4
1 | R16 | 1k | Resistor_SMD:R_0603_1608Metric | Serie Reed 3
1 | R17 | 1k | Resistor_SMD:R_0603_1608Metric | Serie Reed 4
1 | SW1 | RESET | Button_Switch_SMD:SW_SPST_TL3342
1 | SW2 | BOOT | Button_Switch_SMD:SW_SPST_TL3342
1 | U1 | ESP32-S3-WROOM-1-N16R8 | RF_Module:ESP32-S3-WROOM-1 | Antenne zeigt zur Front (+Y), Keepout auf allen Lagen
1 | U2 | MAX3485 | Package_SO:SOIC-8_3.9x4.9mm_P1.27mm | 3,3-V-Typ; Pinbelegung gegen Datenblatt pruefen
1 | U3 | PCF8575 | Package_SO:SSOP-24_5.3x8.2mm_P0.65mm | Adresse 0x20: A0=A1=A2=GND - muss zur YAML passen
1 | U4 | PhotoMOS 60V | Package_SO:SOP-4_4.4x2.6mm_P1.27mm | 1 Form A, SELV - NICHT fuer Netzspannung

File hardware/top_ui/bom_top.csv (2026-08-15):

Menge | Designator | Wert | Footprint | Hinweis
2 | C1,C3 | 100n | Capacitor_SMD:C_0603_1608Metric
1 | C2 | 22u | Capacitor_SMD:C_1210_3225Metric
1 | C4 | 4u7 | Capacitor_SMD:C_0603_1608Metric
1 | F1 | 0,2 A PTC | Fuse:Fuse_1206_3216Metric | Haltestrom > 100 mA, Ausloesestrom < 400 mA
1 | J1 | USB-C | Connector_USB:USB_C_Receptacle_G-Switch_GT-USB-7051x | G-Switch GT-USB-7051A/B, vertikal SMT (LCSC C2843970) - Bauhoehe gegen die 4,5 mm bis zur Scheibe pruefen
1 | J2 | J_STK_A | Connector_PinSocket_1.27mm:PinSocket_2x20_P1.27mm_Vertical
1 | J3 | J_STK_B | Connector_PinSocket_1.27mm:PinSocket_2x20_P1.27mm_Vertical
1 | J5 | ST7789 240x280 | Connector_PinHeader_1.27mm:PinHeader_1x10_P1.27mm_Vertical | PLATZHALTER - reales Modul mit FPC vermessen, dann Footprint und Pinzahl tauschen (Module haben meist 8 Pins)
1 | J6 | Stern Klinke | Connector_Audio:Jack_3.5mm_QingPu_WQP-PJ398SM_Vertical_CircularHoles | PLATZHALTER 3,5 mm vertikal - Zielteil 2,5 mm, Bauhoehe max 10,5 mm ueber der Platine, Footprint aus dem Datenblatt uebernehmen
1 | J7 | Reserve UART | Connector_JST:JST_PH_B5B-PH-K_1x05_P2.00mm_Vertical | DNP - Reserve fuer ein Satellitenmodul
1 | Q1 | BC847 | Package_TO_SOT_SMD:SOT-23
1 | Q2 | P-FET 20V 1A | Package_TO_SOT_SMD:SOT-23 | z.B. AO3401 - 80 mA Last, unkritisch
2 | R1,R2 | 5k1 | Resistor_SMD:R_0603_1608Metric
1 | R3 | 10k | Resistor_SMD:R_0603_1608Metric
1 | R4 | 100k | Resistor_SMD:R_0603_1608Metric | Gate-Pull-up: aus ohne Ansteuerung
1 | R5 | 10k | Resistor_SMD:R_0603_1608Metric | XSHUT-Pullup: Sensor immer aktiv
1 | SW1 | BTN1 | Button_Switch_SMD:SW_Push_SPST_NO_Alps_SKRK | Alps SKRK o.ae., 3,9x2,9 - Ecke oben rechts, unter dem Druckkreuz der Zentralscheibe
1 | SW2 | BTN2 | Button_Switch_SMD:SW_Push_SPST_NO_Alps_SKRK | Alps SKRK o.ae., 3,9x2,9 - Ecke oben links, unter dem Druckkreuz der Zentralscheibe
1 | SW3 | BTN3 | Button_Switch_SMD:SW_Push_SPST_NO_Alps_SKRK | Alps SKRK o.ae., 3,9x2,9 - Ecke unten links, unter dem Druckkreuz der Zentralscheibe
1 | SW4 | BTN4 | Button_Switch_SMD:SW_Push_SPST_NO_Alps_SKRK | Alps SKRK o.ae., 3,9x2,9 - Ecke unten rechts, unter dem Druckkreuz der Zentralscheibe
1 | U1 | USBLC6-2SC6 | Package_TO_SOT_SMD:SOT-23-6
1 | U2 | SHT40-AD1B | Sensor_Humidity:Sensirion_DFN-4_1.5x1.5mm_P0.8mm_SHT4x_NoCentralPad | Adresse 0x44 - muss zur YAML passen; thermisch vom Board entkoppeln (Schlitze)
1 | U3 | VL53L1X | Sensor_Distance:ST_VL53L1x | Optikfenster freihalten, Uebersprechen: Loch konisch aufweiten

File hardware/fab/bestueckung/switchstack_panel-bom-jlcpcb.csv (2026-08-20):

Comment | Designator | Footprint | LCSC Part #
0,2 A PTC | T_F1 | Fuse_1206_3216Metric | C207035
0.5A | B_F2 | Fuse_1812_4532Metric
0R | B_R12,B_R_M1_LNK,B_R_M2_LNK | R_0603_1608Metric | C21189
100k | B_R1,B_R10,B_U2_RT_R,B_U4_RT_R,T_R4,T_R_BLG | R_0603_1608Metric | C25803
100n | B_C1,B_C10,B_C_M1_CS,B_C_M2_CS,B_U2_CB,B_U4_CB,M_C10,M_C2,M_C5,M_C6,M_C7,M_C8,M_C9,T_C1,T_C3 | C_0603_1608Metric | C14663
100u/35V Polymer | B_C_M1_BR,B_C_M2_BR | CP_Elec_8x6.5
10k | B_R_M1_PU,B_R_M2_PU,B_U2_RC,B_U4_RC,M_R1,M_R10,M_R14,M_R15,M_R2,M_R9,T_R3,T_R5 | R_0603_1608Metric | C25804
10k0 | B_R7,B_R9,B_U4_RL | R_0603_1608Metric | C25804
10k2 | B_U2_RL | R_0603_1608Metric
10u | M_C1 | C_0805_2012Metric | C15850
10u | B_C2 | C_1210_3225Metric
10u | B_U2_L | L_Bourns_SRP7028A_7.3x6.6mm | C2687402
120R | M_R5 | R_0603_1608Metric | C22787
12V | B_D2 | D_SOD-123 | C177013
15A flink | B_F1 | Fuse_Littelfuse-NANO2-451_453
180k | B_R5 | R_0603_1608Metric | C22827
1M | B_R1B | R_0603_1608Metric | C22935
1k | B_R11,B_R_M1_F,B_R_M2_F,M_R11,M_R12,M_R16,M_R17,M_R8 | R_0603_1608Metric | C21190
1n | B_C_M1_F,B_C_M2_F | C_0603_1608Metric | C1588
1u | M_C3,M_C4 | C_0603_1608Metric | C15849
220u/35V Polymer | B_C3,B_C4 | CP_Elec_8x6.5
22u | B_C7,B_C8,B_C9,B_U4_CO,T_C2 | C_1210_3225Metric | C52306
2u2 | B_L1 | L_Bourns_SRP5030T
330R | M_R13 | R_0603_1608Metric | C23138
33V | M_D4 | D_SOD-123 | C545300
33k0 | B_R_M1_IL,B_R_M2_IL | R_0603_1608Metric | C4216
33u | B_U4_L | L_Bourns_SRP7028A_7.3x6.6mm | C2046760
392k | B_R3 | R_0603_1608Metric
39R | T_R_BL | R_0603_1608Metric
3n3 | B_U2_CZ,B_U4_CZ | C_0603_1608Metric | C1613
40V | M_D1 | D_SOD-123 | C8598
40V 3A | B_D4,B_D5 | D_SMA | C84635
40k2 | B_R6,B_R8 | R_0603_1608Metric | C12447
47u | B_U2_CO | C_1210_3225Metric
4k7 | M_R6,M_R7 | R_0603_1608Metric | C23162
4u7 | T_C4 | C_0603_1608Metric | C19666
53k6 | B_U2_RH | R_0603_1608Metric
560R | M_R3,M_R4 | R_0603_1608Metric | C23204
5V6 | M_D2,M_D3,M_D5,M_D6 | D_SOD-123 | C78726
5k1 | M_R18,M_R19 | R_0603_1608Metric | C23186
5m0 1W | B_R_M1_SH,B_R_M2_SH | R_2512_6332Metric | C5375417
60V 3A | B_U2_D,B_U4_D | D_SMB | C145306
68k1 | B_U4_RH | R_0603_1608Metric
74AHC1G08 | B_UM1_GA,B_UM1_GB,B_UM2_GA,B_UM2_GB | SOT-353_SC-70-5 | C12490
74AUP1G74 | B_UM1_FF,B_UM2_FF | VSSOP-8_2.3x2mm_P0.5mm | C140267
88k7 | B_R4 | R_0603_1608Metric
BC847 | M_Q2,T_Q1 | SOT-23 | C181141
BOOT | M_SW2 | SW_SPST_TL3342
BTN1 | T_SW1 | SW_SPST_SKQG_WithStem | C115351
BTN2 | T_SW2 | SW_SPST_SKQG_WithStem | C115351
BTN3 | T_SW3 | SW_SPST_SKQG_WithStem | C115351
BTN4 | T_SW4 | SW_SPST_SKQG_WithStem | C115351
DRV8871 | B_UM1_BR,B_UM2_BR | HSOP-8-1EP_3.9x4.9mm_P1.27mm_EP2.41x3.1mm_ThermalVias | C75864
ER-TFT1.69-3 | T_J5 | FPC_Loetfeld_12x0.7mm
ESP32-S3-WROOM-1-N16R8 | M_U1 | ESP32-S3-WROOM-1 | C2913202
Feld 16p | B_J1 | Molex_Micro-Fit_3.0_43045-1612_2x08_P3.00mm_Vertical
HAUPT | T_SW5 | SW_DIP_SPSTx01_Slide_Copal_CVS-01xB_W5.9mm_P1mm
INA240A2 | B_UM1_CS,B_UM2_CS | SOIC-8_3.9x4.9mm_P1.27mm | C2060768
J_STK_A | B_J2,M_J2,T_J2 | PinSocket_2x20_P1.27mm_Vertical
J_STK_B | B_J3,M_J3,T_J3 | PinSocket_2x20_P1.27mm_Vertical
MAX3485 | M_U2 | SOIC-8_3.9x4.9mm_P1.27mm | C18148
N-FET 30V 1A | T_Q_BL | SOT-23 | C20917
P-FET 20V 1A | T_Q2 | SOT-23 | C15127
P-FET 40V 30A | B_Q1 | PowerPAK_SO-8_Single
PCF8575 | M_U3 | SSOP-24_5.3x8.2mm_P0.65mm | C12251
PhotoMOS 60V | M_U4 | SOP-4_4.4x2.6mm_P1.27mm | C1525231
Piezo passiv SMD | M_BZ1 | Buzzer_Murata_PKMCS0909E | C910763
RESET | M_SW1 | SW_SPST_TL3342
SHT40-AD1B | T_U2 | Sensirion_DFN-4_1.5x1.5mm_P0.8mm_SHT4x_NoCentralPad | C2909890
SMBJ30A | B_D1 | D_SMB | C353368
Stern (intern) | T_J6 | JST_GH_SM02B-GHS-TB_1x02-1MP_P1.25mm_Horizontal | C189893
TLV3702 | B_UM1_CMP,B_UM2_CMP | SOIC-8_3.9x4.9mm_P1.27mm
TLV62569 | B_U3 | SOT-23-5 | C141836
TPS54360 | B_U2,B_U4 | HSOP-8-1EP_3.9x4.9mm_P1.27mm_EP2.41x3.1mm | C44377
USB-C | M_J7 | USB_C_Receptacle_G-Switch_GT-USB-7051x | C2843970
USBLC6-2SC6 | M_U5 | SOT-23-6 | C7519
VL53L1X | T_U3 | ST_VL53L1x

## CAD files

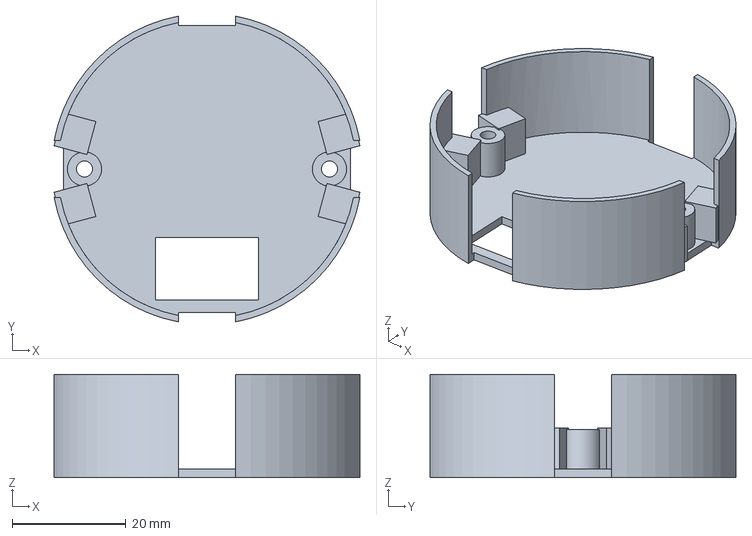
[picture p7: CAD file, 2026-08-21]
mechanical/export/gehaeuse.step
53.7 x 53.7 x 18.1 mm

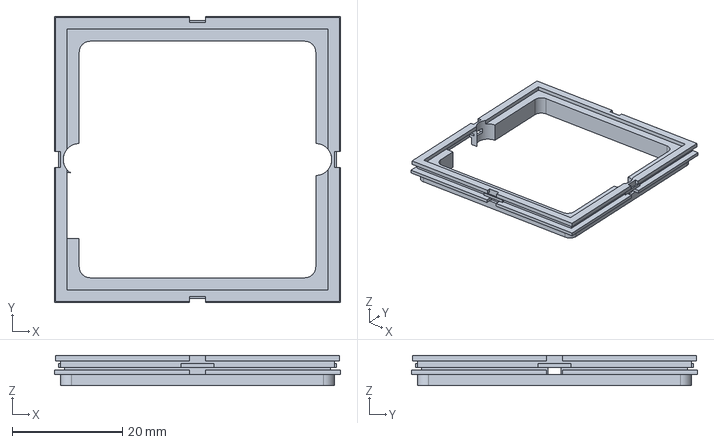
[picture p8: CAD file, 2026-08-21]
mechanical/export/adapter.step
52.0 x 52.0 x 5.50 mm

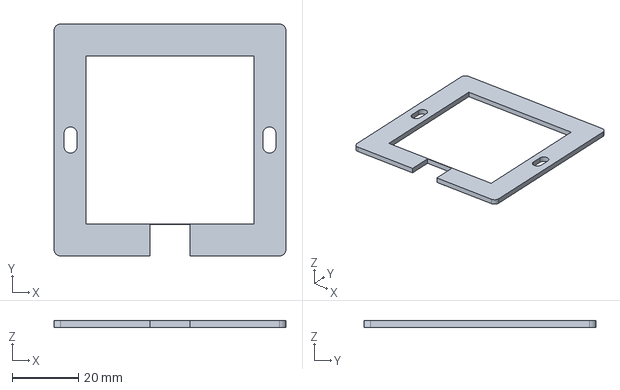
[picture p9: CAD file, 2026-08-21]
mechanical/export/tragring.step
70.0 x 70.0 x 2.00 mm

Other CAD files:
mechanical/export/adapter.stl
mechanical/export/gehaeuse.stl
mechanical/export/tragring.stl

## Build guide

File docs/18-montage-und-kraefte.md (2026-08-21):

# 18 – Einbaureihenfolge und Kraftfluss der Front

Stand **19.08.2026**. Diese Datei beantwortet zwei Fragen, die bisher über
[`04-mechanical.md`](04-mechanical.md), [`../mechanical/adapter.py`](../mechanical/adapter.py)
und die Kommentare in [`../tools/gen_layouts.py`](../tools/gen_layouts.py) verstreut
waren:

1. **In welcher Reihenfolge wird gefügt** — und an welchen Stellen ist die
   Reihenfolge zwingend, weil sonst etwas nicht mehr zugänglich oder nicht mehr
   montierbar ist?
2. **Wer hält wen** — wo wird geschraubt, geklemmt, geklebt, gerastet oder
   magnetisch gehalten, und wo werden Toleranzen aufgefangen?

Alle Zahlen sind aus dem Quelltext gelesen, nicht nachgerechnet:
`PARAMS` und `_z()` in `mechanical/adapter.py`, die Höhenkette in
`mechanical/stack.py`, die Konstanten `TOP_SQ`, `MAG_X/MAG_Y/MAG_D`,
`NOTCH_*`, `STACK_POS`, `STACK_SIDE` in `tools/gen_layouts.py` sowie das
Messprotokoll F1–F13 in [`04-mechanical.md`](04-mechanical.md) Abschnitt 1d.

> **Was dieses Dokument nicht ist.** Es ist keine Festigkeitsrechnung und kein
> Montageversuch. Jede Aussage, die nicht direkt aus einer Zahl im Quelltext
> folgt, ist unten als **ungeprüft** markiert und in
> [`06-open-decisions.md`](06-open-decisions.md) als Punkt 60–65 nachgetragen.

---

## 1. Die fünf Teile

| Teil | Herkunft | Aufgabe im Verbund |
|---|---|---|
| **Abdeckrahmen 1721-914** | Serienteil, 81 × 81 × 12 mm, Fenster 56,0 (F11) | Sichtblende; klemmt auf den Adapterflansch, verdeckt die Geräteschrauben |
| **Zentralscheibe 6435-914** | Serienteil, 55,2 × 55,2 × 7,5 mm (F1/F2) | Sichtfläche, Tastenbeschriftung, Displayfenster 32,7 × 27,0 — und **das einzige Teil, das ohne Werkzeug abgeht** |
| **3D-Adapter** | `mechanical/adapter.py`, 70 × 70 × 10,0 mm | Tragring, Rahmenhalt und Platinenträger in einem Teil |
| **Top-Board** | 47 × 47 mm, R 4, 1,0 mm dick | trägt Display, vier Ecktaster, ToF, Raumsensor, Magnetkontakt |
| **Displaypanel ER-TFT1.69-3** | 30,07 × 37,43 × 1,6 mm, 12-polige FPC | liegt zwischen Board und Scheibe, **aufgeklebt** |

Die Tiefenkette, von der Sichtfläche nach hinten (`04-mechanical.md` 1e):

```
0,0 … 1,0   Sichtfläche der Zentralscheibe        (F1)
1,0 … 2,5   Druckkreuze auf ihrer Rückseite       (F10, 1,5 hoch)
2,5 … 4,5   SMD-Taster über der Leiterplatte      (2,0 hoch)
4,5 … 5,5   Top-Leiterplatte                      (1,0)
      7,5   Rastebene, hintere Kante der Scheibe  (F2)
```

### Die Zeichnung dazu

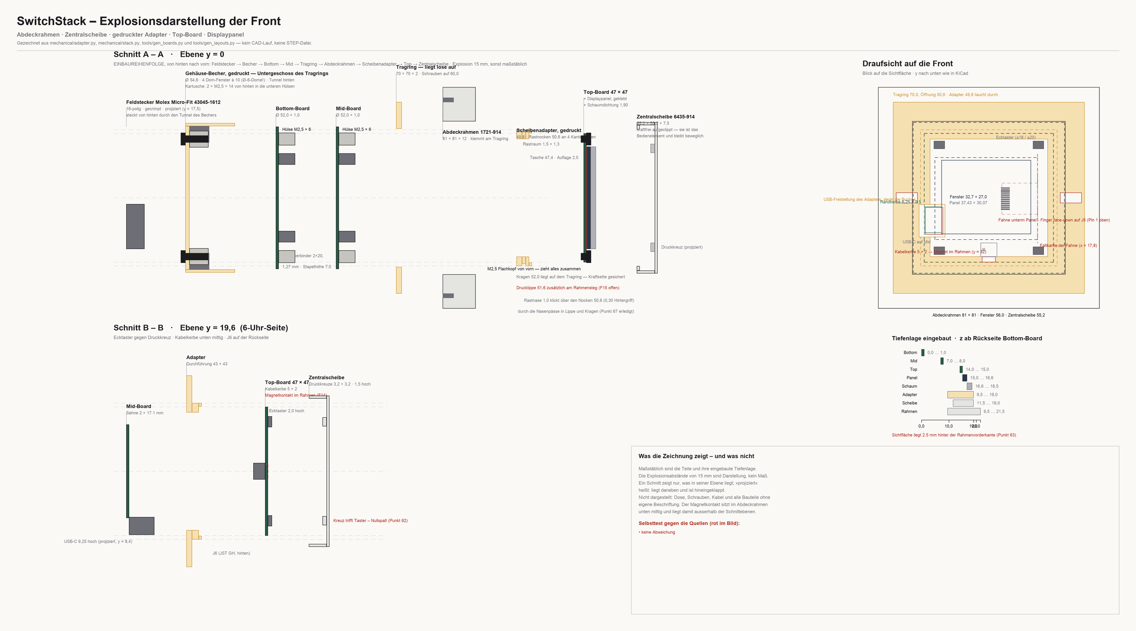
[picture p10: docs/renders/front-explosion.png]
Maßstäbliche Schnitte durch Abdeckrahmen, Zentralscheibe, Adapter, Top-Board und Displaypanel


Erzeugt von [`../tools/gen_explosion.py`](../tools/gen_explosion.py) →
`renders/front-explosion.png`. Sie enthält zwei Schnittebenen, die Draufsicht
und die eingebaute Tiefenlage.

**Was sie zeigt:** die fünf Teile maßstäblich in Höhe *und* Tiefe, ihre
eingebaute z-Lage, und rot markiert die offenen Punkte an genau der Stelle, an
der sie auftreten.

**Was sie nicht zeigt:** kein 3D. Ein Schnitt zeigt nur, was in seiner Ebene
liegt; alles, was als *projiziert* beschriftet ist, liegt daneben und ist
hineingeklappt. Die Explosionsabstände von 13 mm sind Darstellung, kein Maß.
Nicht dargestellt sind Dose, Schrauben, Kabel und alle Bauteile ohne eigene
Beschriftung. Der Magnetkontakt ist ein Platzhalter (Punkt 64).

Die Zahlen liest das Werkzeug mit `ast` direkt aus `adapter.py`, `stack.py`,
`gen_boards.py` und `gen_layouts.py` — es kann also nicht auseinanderlaufen,
und ein CAD-Lauf ist dafür nicht nötig. Die 57 MB große
`switchstack_stack.step` wird bewusst **nicht** geladen.

**Die Rastebene liegt hinter der Leiterplatte.** Daraus folgt der ganze Aufbau:
Der Schnapprand des Adapters steht hinter dem Board und ist Rastglied und
Auflage in einem. In der Displayfläche gilt eine eigene Kette — 1,90 mm Luft
für die Schaumdichtung, 1,60 mm Panel, 0,1–0,2 mm Klebefuge.

---

## 2. Einbaureihenfolge

### Stufe A — Top-Board vormontieren (alles, was hinterher unerreichbar ist)

| # | Schritt | Warum genau hier |
|---|---|---|
| A1 | **Displaypanel auf die Vorderseite kleben** — doppelseitiges Band umlaufend, 2,40 mm an den langen, 1,05 mm an den kurzen Seiten | Die Klebefläche liegt unter dem Panel. Ist der Stapel gefügt, kommt niemand mehr an sie heran; die Sperrfläche `block_f` hält sie im Layout frei |
| A2 | **FPC um die Boardkante falten und in J5 stecken** (J5 sitzt auf der **Rückseite**, (0 / 3,0)) | Die Fahne ist 18,15 mm lang und laut Zeichnung ohnehin gefaltet. Nach dem Stecken von Mid liegen nur noch 10,0 mm Spalt vor der Buchse |
| A3 | **Magnetkontakt in den Durchbruch Ø 6,7 bei (−10,0 / 19,6) setzen**, Litzen nach hinten | Sein Körper taucht nach hinten in den 10-mm-Spalt; vorn bleibt nur der Flansch. Vor dem Board sind nur 3,50 mm frei — nach dem Stapeln ist der Durchbruch von hinten verbaut. **Wie der Kontakt befestigt wird, ist offen (Punkt 64)** |
| A4 | **Sternlitzen in J6 stecken** (Rückseite, (−17,0 / 19,6)) | Gleicher Grund: J6 zeigt nach hinten zu Mid |

**Zwingend**, weil jeder dieser vier Schritte auf einer Fläche stattfindet, die
danach entweder verklebt (A1) oder von Mid in 10,0 mm Abstand verdeckt ist
(A2–A4). Ob 10,0 mm für Steckerarbeit von der Seite genügen, ist **ungeprüft**
(Punkt 64).

### Stufe B — Stapel fügen

| # | Schritt | Warum genau hier |
|---|---|---|
| B1 | **Top auf Mid stecken** — Stackverbinder bei x = ±14,2, Stapelhöhe 7,0 mm | Mid trägt die USB-C-Buchse auf seiner Vorderseite (3,5 / 20,3); sie **greift durch die Randkerbe** des Top-Boards (6,25 × 9,5 mm, linker Rand). Steckt man verdreht, stößt der Buchsenkörper gegen das Board statt durch die Kerbe |
| B2 | **Mid auf Bottom stecken** — wieder 10,0 mm | Bottom↔Mid trägt keine Sonderteile; die Reihenfolge B1/B2 ist frei tauschbar |
| B3 | **Kabelbaum an den Bottom-Connector** (Micro-Fit 3.0, 2×8) | Hinter Bottom sind laut Tiefenbudget nur 12,0 mm Steckraum plus Kabelbogen vorgesehen; in der Dose ist der Stecker nicht mehr bequem zu treffen |

**Verdrehsicherung übernehmen die beiden Stackverbinder** — sie liegen auf
allen drei Boards deckungsgleich. Eine Codierung A/B ist noch nicht ausgewählt
(Punkt 23), damit ist Verpolungssicherheit derzeit **nicht** gegeben.

### Stufe C — Adapter aufsetzen und in die Dose schrauben

| # | Schritt | Warum genau hier |
|---|---|---|
| C1 | **Adapter von vorn über das Top-Board schieben**, bis das Board auf der 2,0-mm-Auflage aufsitzt | Die Auflage liegt **hinter** dem Board. Der Adapter kann nur von vorn kommen: Seine zentrale Durchführung misst 43 × 43 mm, die Boards messen 47 bzw. Ø 52 — über Mid ließe er sich nicht fädeln. Die Stackverbinder passen mit (16,25 / 13,2) durch die Durchführung, dafür ist sie da |
| C2 | **Lage prüfen: die USB-Freistellung des Adapters muss auf dieselbe Seite wie die Randkerbe zeigen** | Der Adapter ist seit dem 18.08.2026 **nicht mehr punktsymmetrisch**. Die Freistellung (x −1,2 … 8,2, bis y 24,0) liegt auf der 6-Uhr-Seite. Falsch herum stößt der Buchsenkörper vom Mid-Board gegen den Auflagesteg |
| C3 | **Stapel in die Dose einführen und den Adapter mit zwei Geräteschrauben auf 60 mm anziehen** | Die Langlöcher liegen bei x = ±30,0 und damit außerhalb der Boards (r = 26) und außerhalb der Zentralscheibe (55,2) — sie sind nur zugänglich, **solange der Rahmen ab ist** |

### Stufe D — Front schließen

| # | Schritt | Warum genau hier |
|---|---|---|
| D1 | **Abdeckrahmen aufklemmen** — Doppelstege auf 70,0 mm (F13) | Erst nach dem Anziehen: Der Rahmen verdeckt die Schraubschlitze |
| D2 | **Zentralscheibe aufrasten** — vier Nasen auf lichte 50,0 (F8) gegen den Rand 49,8 | Letzter Schritt, und der einzige, der werkzeuglos rückgängig ist. Erst damit ist das Top-Board nach vorn gesichert (siehe Abschnitt 3) |

### Was die Reihenfolge erzwingt — Kurzfassung

* **A vor B**, weil Klebefläche, FPC-Buchse, Magnetdurchbruch und J6 danach im
  10-mm-Spalt liegen.
* **B vor C1** *oder* C1 vor B — geometrisch beides möglich, solange Mid nicht
  vor dem Adapter am Top hängt und der Adapter dann noch übergefädelt werden
  müsste. Praktisch ist B vor C, weil sich der Stapel auf dem Tisch stecken
  lässt.
* **C3 vor D1**, weil der Rahmen die Schrauben verdeckt.
* **D1 vor D2** ist Konvention, keine Zwangsbedingung; ob die Scheibe später
  abgenommen werden kann, **ohne den Rahmen mitzureißen**, ist der ausdrücklich
  offene Teil von Punkt 25.
* **Für den USB-Zugang gilt der umgekehrte Weg nur bis D2:** Scheibe ab, Buchse
  frei. Rahmen und Schrauben bleiben unberührt — genau dafür ist der Aufbau
  gemacht (Punkt 45).

---

## 3. Wer hält wen

Von außen nach innen. Die Spalte **Toleranzglied** sagt, was die Passung
auffängt — und wo nichts steht, fängt nichts auf.

| Fügestelle | Art | Maß | Toleranzglied |
|---|---|---|---|
| **Adapter ↔ Gerätedose** | **verschraubt**, zwei Geräteschrauben nach DIN 49073 | Langlöcher 3,9 mm breit, 7,9 mm über alles, Achsabstand 60,0 | Das Langloch — es fängt die Lochbild- und Verdrehtoleranz der Dose radial auf. **Das gesamte Gerätegewicht hängt hier**, in gedrucktem Kunststoff mit 2,5 mm Flansch (Punkt 51) |
| **Rahmen ↔ Adapter** | **geklemmt**, Doppelstege des Rahmens | Innenmaß 70,0 gegen Flansch 70,0 × 70,0, Ecken R 2,0 | **keines** — Null-Spiel-Paarung. Der Rahmen hält nur sich selbst; F13 nennt die Stege „eher Justierung als Halt". Wie fest er wirklich sitzt: ungeprüft (Punkt 25) |
| **Zentralscheibe ↔ Adapter** | **aufgesteckt** — vier Nasen mittig je Kante, aber **ohne Hintergriff** | Rand außen 49,8 gegen lichtes Rastmaß 50,0 → **0,1 mm Luft je Seite**. Der Rastraum springt zwar 1,5 mm zurück, doch die Nasenspitzen liegen mit 25,0 *außerhalb* der Schulter (24,9) — sie gleiten über den Rand, statt dahinterzugreifen | `rim_play` = 0,2 mm gesamt, ausdrücklich als *Untermaß* geführt. Damit hält die Scheibe rechnerisch nur durch Reibung — **Punkt 67** |
| **Top-Board ↔ Adapter** | **eingelegt und hintergriffen** — Tasche seitlich, Auflage hinten | Tasche 47,4 für Board 47,0 → 0,2 mm je Seite; Auflage 2,0 mm ringsum, unterbrochen von der 9,4 mm breiten USB-Freistellung | `pcb_play` = 0,4 mm gesamt fängt die Fräßtoleranz des Boards auf. **Nach vorn hält nichts** — das übernimmt die Scheibe |
| **Zentralscheibe ↔ Top-Board** | **Anpressung über die vier Druckkreuze** | Kreuze 3,2 × 3,2 mm bei (±18,0 / ±20,0), 1,5 mm hoch, treffen die Taster | **keines** — siehe Abschnitt 4. Die Scheibe ist zugleich das einzige Teil, das das Board am Herausfallen hindert; ist sie ab, liegt das Board lose in der Tasche |
| **Displaypanel ↔ Top-Board** | **geklebt**, doppelseitiges Band umlaufend | 2,40 mm lange Seiten, 1,05 mm kurze Seiten; Klebefuge 0,1–0,2 mm | Die Klebefuge. **Bewusst geklebt und nicht geklemmt:** Die Schaumdichtung in den 1,90 mm davor drückt an, darf aber nicht die Befestigung sein — sonst fällt das Panel heraus, sobald die Scheibe abgenommen wird |
| **FPC ↔ J5** | **gesteckt**, 12-polige FPC-Buchse auf der Rückseite | Fahne 18,15 mm, gefaltet um die Boardkante | Die Faltung. Raster (0,5 oder 0,7 mm) und Pinbelegung sind noch offen (Punkt 15c, `17-bauteildaten.md`) |
| **Magnetkontakt ↔ Top-Board** | **im Durchbruch Ø 6,7 gehalten** — „die Platine hält ihn" (`adapter.py`) | Körper 6,5 + 0,2 Spiel; freier Streifen zwischen Panelkante (y 15,9) und Boardkante (23,5) beträgt 7,6 mm | **Die Befestigungsart ist nirgends festgelegt** — Flansch vorn, Mutter hinten, Kleber? Punkt 64 |
| **Sternstecker ↔ Magnetkontakt** | **magnetisch** | Maße sind Platzhalter (`magnet_d = None`, `magnet_h = 3,0`) | Haltekraft, Abzugskraft und Kontaktwiderstand unbekannt — zum Teil (Elsaybro) gibt es kein Datenblatt |
| **Top ↔ Mid ↔ Bottom** | **gesteckt**, zwei Stackverbinder 2×20, 1,27 mm, Stapelhöhe 7,0 mm | x = ±14,2, y = −2,0; auf allen drei Boards deckungsgleich | **keines, und kein Distanzbolzen** — der Plattenabstand soll aus der Steckhöhe kommen. Das Bauteil ist noch nicht ausgewählt (Punkt 23); heute sitzt dreimal dieselbe Buchse |
| **Mid, Bottom ↔ Dose** | **nichts** | — | Beide hängen ausschließlich an den Stackverbindern am Top-Board, das seinerseits in der Adaptertasche liegt. Die Befestigungsbohrungen M2,5 auf r = 21,5 haben **im Adapter kein Gegenstück** (Punkt 61) |

### Der Kraftweg in einem Satz

Gewicht und Bedienkraft des ganzen Geräts laufen über **zwei gedruckte
Schraubaugen** in die Dose; alles andere hängt in Reihe daran — Rahmen geklemmt,
Scheibe aufgesteckt, Top-Board in der Tasche liegend, Mid und Bottom an zwei
Steckverbindern.

> **Korrektur 19.08.2026.** Hier stand zuvor „Scheibe gerastet, 0,75 mm
> radialer Eingriff je Seite". Die 0,75 mm sind die Stufentiefe des
> Adapterrandes (49,8 gegen Rastraum 48,3), **nicht** der Eingriff der Nasen:
> Deren lichtes Maß ist 50,0 und liegt damit 0,1 mm je Seite *außerhalb* des
> Randes. Aufgefallen beim maßstäblichen Zeichnen — siehe Abschnitt 7 und
> Punkt 67.

---

## 4. Wo Toleranzen aufgefangen werden — und wo nicht

**Aufgefangen wird an vier Stellen:** Langloch (Dose), Taschenspiel 0,4 mm
(Board), Klebefuge 0,1–0,2 mm (Panel) und die 1,90 mm Schaumdichtung vor dem
Panel. Das ist die einzige echte Federung im ganzen Frontaufbau.

**Nicht aufgefangen wird an drei Stellen**, und alle drei sind neu benannt:

1. **Taster gegen Druckkreuz — Nullspalt.** Die Tiefenkette setzt die
   Kreuzunterkante auf 2,5 und die Tasteroberkante ebenfalls auf 2,5. Nominal
   berühren sie sich spannungsfrei. Die Kette hat aber kein nachgiebiges Glied:
   Drucktoleranz der Auflage, Platinendicke ±, Bauhöhe des Tasters und Tiefe der
   Scheibe addieren sich direkt auf den Schaltweg. Zu klein heißt Dauerdruck auf
   allen vier Tastern, zu groß heißt Leerweg und schwammiger Druckpunkt.
   → **Punkt 62, ungeprüft.**
2. **Flansch gegen Rahmen — Null-Spiel-Klemmung** auf 70,0/70,0. Ein FDM-Druck
   fällt üblicherweise über Maß aus; der Rahmen ist ein Spritzteil und gibt
   nicht nach. → gehört zu Punkt 25.
3. **Lage der Sichtfläche im Rahmen.** Der Adapter baut 10,0 mm vor der Wand,
   der Rahmen ist 12 mm tief. Rechnerisch liegt die Sichtfläche der Scheibe
   damit **rund 2 mm hinter der Rahmenvorderkante** — F12 hat am realen Teil
   dagegen „bündig" ergeben. Der Selbsttest prüft nur, dass der Adapter unter
   dem Rahmen verschwindet (`z_total ≤ frame_depth`), nicht, wo die Sichtfläche
   landet. → **Punkt 63, ungeprüft.**

---

## 5. Strompfade über Lagenwechsel — Vias sind nicht beliebig belastbar

Angestoßen am 19.08.2026, gehört ins spätere Routing und ist hier festgehalten,
damit es nicht wieder verlorengeht.

Die Belastbarkeit eines Vias hängt an **Bohrdurchmesser, Kupferdicke in der
Hülse, Länge (also dem Lagenabstand) und der zulässigen Übertemperatur**. Keine
dieser vier Größen ist im Projekt festgelegt:

| Größe | Stand |
|---|---|
| Via-Geometrie | 0,6 / 0,3 mm (`15-bestellung.md`) — als Fertigungsgrenze, nicht als Strombemessung |
| Kupfer der Lagen | 1 oz (`05-manufacturing.md` Abschnitt 1) |
| **Kupferdicke in der Hülse** | **nirgends festgelegt** — sie ist unabhängig von der Lagendicke und beim Fertiger zu bestätigen |
| Lagenaufbau / Bohrlänge | „beim Fertiger zu bestätigen" |
| zulässige Übertemperatur | nicht benannt; `05` warnt nur allgemein, dass Leiterbahnrechner freie Konvektion voraussetzen und in der geschlossenen Dose optimistisch sind |

Die vorhandene Regel lautet: *„Vias in Hochstrompfaden ausreichend dimensionieren
und **mehrfach** setzen"* (`05-manufacturing.md` Abschnitt 2). Das ist eine
Haltung, keine Prüfgröße — ohne Zahl lässt sich nicht feststellen, ob ein Layout
sie erfüllt.

**Wo im Gerät Strom die Lage wechselt** (aus den Platzierungsdaten, das Routing
selbst ist für Mid und Top noch offen):

| Pfad | Warum ein Lagenwechsel unvermeidlich ist |
|---|---|
| **Versorgung auf dem Top-Board** — `5V_SYS`, `3V3_SYS`, `PGND` | Die Stackverbinder sitzen auf der **Rückseite** (`STACK_SIDE["top_ui"] = "B"`), praktisch alle Verbraucher (Display-Backlight, ToF, Raumsensor, Taster) auf der Vorderseite. Jedes Ampere geht durch Vias |
| **Sternpfad** `6V2_STAR_F` → P-FET → PTC → `STAR_OUT` → J6 | `6V2_STAR_F` kommt über **einen einzigen** Stackpin (Pin 13) herauf, die Schaltstufe liegt vorn, J6 liegt hinten. Der Router hat `STAR_OUT` bereits auf B.Cu gelegt (`05-manufacturing.md`) — der Pfad quert also mindestens zweimal die Lage |
| **`USB_VBUS`** | Buchse auf Mid vorn, Weiterführung über den Stack nach Bottom auf **einem** Pin (18) |
| **Motorpfade auf dem Bottom-Board** — `24V_IN±`, `M1_A/B`, `M2_A/B`, Shunt-Rückpfad | 4,1 A Summe, 1,7 A je Motor im Fahrbetrieb. Vierlagig geroutet mit heute 102 Vias; welche davon im Strompfad liegen und wie viele parallel, ist nicht ausgewertet |

**Festzuhalten für das Routing (Punkt 60):** Für jeden dieser Pfade ist die
Zahl paralleler Vias aus dem Strom, der Hülsenkupferdicke und einer *benannten*
Übertemperatur zu bestimmen — und nicht anzunehmen, ein einzelnes Via genüge.
Das gilt besonders dort, wo ohnehin schon ein einzelner Kontakt der Engpass ist
(`6V2_STAR_F`, `USB_VBUS`): Ein Pin und ein Via hintereinander addieren ihre
Erwärmung im selben, luftlosen Volumen.

Die verwandte Frage der **Stackpins** ist getrennt und bereits beantwortet:
[`03-stack-pinout.md`](03-stack-pinout.md) Abschnitt 2 rechnet mit ≈ 1 A je
Kontakt und verteilt `5V_SYS` auf vier Pins. Für Vias gibt es kein Gegenstück
dieser Tabelle.

---

## 6. Was ungeprüft bleibt

| Thema | Punkt |
|---|---|
| Zentralscheibe rastet rechnerisch nicht ein — 0,1 mm Luft statt Hintergriff | **67** |
| USB-Freistellung des Adapters liegt auf der falschen Seite | **68** |
| Ebenenabstand: 9,0 mm im Modell gegen 10,0 mm im Tiefenbudget | **66** |
| Vias in Strompfaden — Bemessung statt „mehrfach setzen" | **60** |
| Halt von Mid und Bottom; Befestigungsbohrungen ohne Gegenstück im Adapter | **61** |
| Nullspalt zwischen Druckkreuz und Taster | **62** |
| Sichtfläche liegt rechnerisch 2 mm hinter der Rahmenvorderkante | **63** |
| Befestigung des Magnetkontakts, Zugänglichkeit von J6 und J5 im 10-mm-Spalt | **64** |
| Widersprüchliche Quellenlage Klinkenbuchse ↔ JST GH ↔ Magnetkontakt | **65** |
| Rasten, Klemmen, Abnehmen am Testdruck | 25 |
| Halten die gedruckten Schraubaugen | 51 |
| Bauhöhe und Außenmaß des realen Displaymoduls | 15c |
| Stackverbinder-Paar samt Codierung und Steckhöhe | 23 |
| Sicherung der Platine gegen Herausfallen bei abgenommener Scheibe | `../mechanical/README.md`, „Was noch fehlt" |

## 7. Was das maßstäbliche Zeichnen zutage gefördert hat

Vier Dinge, die in den Tabellen nicht auffielen, weil dort jede Zahl für sich
richtig ist. Erst nebeneinander gezeichnet stimmen sie nicht zusammen. Alle
vier prüft `gen_explosion.py` jetzt bei jedem Lauf und schreibt sie ins Bild.

1. **Der Adapter saß in `stack.py` 5,5 mm zu weit vorn** — dort stand 21,0, die
   Koordinate der Board*vorder*seite, gefordert ist die Lage der Auflage auf
   der Board*rück*seite: 20,0 − 4,5 = **15,5**. Korrigiert am 19.08.2026, mit
   Gegenprobe: Mit 15,5 fällt die hintere Kante der Zentralscheibe (18,0)
   genau auf die Flanschvorderkante (15,5 + 2,5). Die Baugruppen-STEP ist
   damit neu zu erzeugen — bis dahin zeigte sie den Adapter schwebend.
2. **Die Zentralscheibe rastet rechnerisch nicht ein** (Punkt 67). Ihr lichtes
   Nasenmaß ist 50,0, der Schnapprand 49,8 — die Nasen gleiten mit 0,1 mm Luft
   je Seite über den Rand, statt hinter der Schulter zu greifen. Der
   Selbsttest in `adapter.py` prüft nur, *dass* der Rand hineinpasst, nie,
   *dass* etwas hält.
3. **Die USB-Freistellung des Adapters liegt auf der falschen Seite**
   (Punkt 68). Sie steht bei x = −1,2…8,2 auf der 6-Uhr-Seite; die Buchse ist
   am 18.08.2026 an den linken Rand gewandert (x = −23,2…−16,8, Kerbe
   −23,5…−17,25). Der Adapter stellt heute eine Stelle frei, an der nichts
   steht, und lässt Material dort stehen, wo der Buchsenkörper durchgreift.
4. **Ein Millimeter Unterschied im Ebenenabstand** (Punkt 66): `stack.py`
   setzt die Boards auf 0/10/20 — zwischen Boardvorderseite und nächster
   Boardrückseite bleiben damit 9,0 mm. Das Tiefenbudget in
   [`04-mechanical.md`](04-mechanical.md) Abschnitt 4 rechnet mit 10,0 mm ab
   Boardvorderseite. Eine der beiden Lesarten ist falsch, und welche, hängt
   daran, wie die Stapelhöhe des noch nicht gewählten Verbinders definiert ist
   (Punkt 23).

**Die Quellenlage ist an einer Stelle widersprüchlich** und wurde hier nicht
stillschweigend geglättet: [`04-mechanical.md`](04-mechanical.md) Abschnitte 6b
und 7 sowie [`13-funktionsstatus.md`](13-funktionsstatus.md) beschreiben den
Sternanschluss noch als **2,5-mm-Klinkenbuchse** mit vier Durchbrüchen in der
Scheibe, während `tools/gen_layouts.py`, `mechanical/adapter.py` und
[`17-bauteildaten.md`](17-bauteildaten.md) seit dem 18.08.2026 den **JST GH auf
der Rückseite plus Magnetkontakt im Boarddurchbruch** führen. Dieses Dokument
folgt dem Quelltext, weil er den jüngeren Stand trägt. Aufgenommen als Punkt 65.

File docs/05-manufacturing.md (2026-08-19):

# 05 – Fertigung

## 1. Lagenaufbau

| Board | Lagen | Kupfer | Begründung |
|---|---|---|---|
| BOTTOM | **4** | **1 oz genügt** | Summenstrom ≈ 4,1 A im ungünstigsten Fall — seit der Blockierstrommessung vom 17.08.2026, siehe [`11-motor-data.md`](11-motor-data.md). Die vorhandenen breiten Bahnen bleiben, schaden nicht und kosten nichts |
| MID | **4** | 1 oz | ESP32-Routingdichte |
| TOP | **4** | 1 oz | wenig Strom, aber zwei dichte Steckverbinder |

Alle drei Boards: **1,0 mm Dicke**. Bottom und Mid Ø 52,0 mm, Top 47 × 47 mm.

> **Vier Lagen für alle drei, entschieden am 17.08.2026.** Zweilagig kam der
> Autorouter nicht durch — nach 200 Passes blieben 75 Signalnetze offen, und
> Freerouting meldete selbst, es könne „not improve the result much further".
> Der Umstieg auf vier Lagen hat das entschieden:
>
> | | zweilagig | vierlagig | Endstand |
> |---|---:|---:|---:|
> | Mid | 18 offen | **2** | 9 |
> | Bottom | 43 offen | **8** | **4** |
> | Top | 14 offen | 11 | **3** |
>
> **Bei Top half die Lagenzahl nichts — und der Grund war ein Fehler im
> Werkzeug.** `route_boards.py` legt dem Router einen Keepout an den Boardrand,
> weil KiCads Specctra-Export den Kupfer-Randabstand nicht mitgibt. Dieser
> Keepout war ein **Kreisring von r = 25,6 bis 26,4** — richtig für die runden
> Boards mit Ø 52, aber auf dem quadratischen Top-Board lag er quer über die
> Platine, und dessen vier Ecktaster sitzen bei r = 26,91, also außerhalb.
> Alle vier Tastennetze waren damit unroutbar, unabhängig von Lagenzahl,
> Routerversion und Pinbelegung. Seit der Keepout der Boardform folgt, fällt
> Top von 11 auf 3 offene Netze.
>
> Für Mid und Bottom haben die vier Lagen dagegen eigenständig gewirkt — sie
> sind rund, der Ring lag bei ihnen richtig.
>
> Die Masseflächen liegen auf **allen vier** Lagen und werden nach dem Routing
> gefüllt; es gibt bewusst keine durchgehende Massefläche auf einer eigenen
> Lage. Das wäre für die EMV besser, kostet aber eine der vier Routinglagen.
> Innen volle Padanbindung, außen Wärmefallen für die Durchsteckteile.

Bei 1,0 mm Gesamtdicke und vier Lagen wird der dielektrische Abstand dünn — das ist
herstellbar, aber der konkrete Stackup ist beim Fertiger zu bestätigen, bevor
Impedanz- oder Isolationsannahmen darauf aufgebaut werden.

Die 2-oz-Frage für Bottom ist erledigt: Bei 4,1 A Summenstrom im ungünstigsten
Fall reicht Standardkupfer. 2 oz erlaubte schmalere Bahnen bei gleicher Erwärmung,
kostet aber Aufpreis und vergrößert die minimalen Strukturbreiten — beides
unnötig.

## Vias und Strom (20.08.2026)

Ein 0,6/0,3-Via trägt rund 1,2 A — `24V_IN` lief über genau eines davon,
bei 4,1 A Summenstrom. Seitdem gilt:

- **Leistungs- und Schienennetze auf Bottom routen mit 0,8/0,4** (~1,6 A);
  Mid und Top hatten das Leistungsvia bereits.
- **`tools/via_check.py` läuft nach jedem Routing**: 4 A je mm Bohrung,
  Vias desselben Netzes im 3-mm-Umkreis zählen parallel. `--fix` setzt
  Zwillingsvias neben unterdimensionierte Übergänge — danach immer DRC.
- Masse-Brücken (`gnd_connect`) setzen auf Bottom ebenfalls 0,8/0,4.

## 2. Leiterbahnauslegung

Für jeden Hochstrompfad ist die Breite gegen den realen Strom zu rechnen, nicht zu
schätzen. Zu prüfende Netze auf dem Bottom-Board:

| Netz | Strom | Bemerkung |
|---|---|---|
| `24V_IN+` / `24V_IN−` | ≈ 4,1 A Spitze, 1,7 A im Fahrbetrieb | Summenpfad beider Motoren; weiterhin der stärkste Pfad, aber unkritisch |
| `M1_A` / `M1_B` | ≈ 4,17 A nominal, Peak offen | je ein Motor |
| `M2_A` / `M2_B` | ≈ 4,17 A nominal, Peak offen | je ein Motor |
| Shunt-Rückpfad | wie Motorzweig | Kelvin-Abgriff nicht in den Strompfad legen |

Regeln:

- Motorstromschleifen kurz und breit halten, Hin- und Rückpfad möglichst übereinander.
- Vias in Hochstrompfaden ausreichend dimensionieren und **mehrfach** setzen.
- Thermische Betrachtung im geschlossenen Gehäuse ohne Luftstrom — die üblichen
  Leiterbahn-Rechner setzen freie Konvektion voraus und sind hier optimistisch.
  Konservativ auslegen.

## 3. Prüfungen vor Fertigungsfreigabe

Pro Projekt abzuarbeiten:

- [ ] **ERC** sauber, verbleibende Meldungen einzeln begründet
- [ ] **DRC** sauber, inklusive Kupfer-zu-Rand-Abstand am Kreisrand
- [ ] Leiterbahnbreiten gegen Strom gerechnet (Abschnitt 2)
- [ ] Thermische Betrachtung der Endstufen und DC/DC-Wandler
- [ ] Alle drei Boards: Bohrbild und Stackverbinder deckungsgleich
  (Koordinaten aus [`04-mechanical.md`](04-mechanical.md))
- [ ] Tiefenbudget mit realen Bauteilhöhen nachgerechnet
- [ ] Steckverbinder-Stromrating gegen Datenblatt bestätigt
- [ ] Antennen-Keepout auf allen Lagen frei
- [ ] Buck-Layouts gegen Hersteller-Referenzlayout verglichen
- [ ] 3D-Ansicht: keine mechanischen Kollisionen im gestapelten Zustand

## 4. Fertigungsdaten

Ausgabe pro Projekt nach `<projekt>/production/`. Dieses Verzeichnis ist in
`.gitignore` ausgenommen — Fertigungsstände werden **bewusst und getaggt** eingecheckt
(`git add -f`), nicht bei jedem Zwischenstand.

Umfang eines Fertigungsstands:

- Gerber (Protel- oder X2-Format nach Fertigervorgabe)
- Excellon-Bohrdaten
- IPC-356-Netzliste für den elektrischen Test
- BOM (CSV) mit Herstellerteilenummern
- Pick-and-Place-Datei
- PDF-Plots von Schaltplan und Assembly-Zeichnung
- README mit Fertiger, Datum, Git-Commit und Stackup-Vorgabe

Empfehlung: pro Fertigungsstand ein Git-Tag der Form
`bottom-v0.1`, `mid-v0.1`, `top-v0.1`, damit der gefertigte Stand später eindeutig
rekonstruierbar ist.

## 5. Routing-Stand und Restarbeiten (2026-08-15)

| Board | Segmente im Repository | Stand |
|---|---:|---|
| **BOTTOM** | **985** (102 Vias) | ≈ 85 % geroutet, 0 Kupferfehler. Offen sind 43 Verbindungen im Motor-/Leistungsteil (SW-Knoten, Gate-Netze, `24V_PROT`). Der Autorouter konvergiert dort nicht mehr — die Leistungspfade sind laut Prüfliste (Abschnitt 3) **ohnehin von Hand zu ziehen**. |
| **MID** | **746** (104 Vias) | Am 16.08.2026 im Container geroutet. Offen: 59 Masseanbindungen (schließt die Zonenfüllung) und **18 Signalverbindungen** auf 16 Netzen. Dazu **fünf Kupferfehler, alle an derselben Stelle**: `HOOD_B` kreuzt `RELAY_LED` bei (12,2 / 19,2), also am PhotoMOS. |
| **TOP** | **197** (12 Vias) | Am 16.08.2026 im Container geroutet. Offen: 57 Masseanbindungen (schließt die Zonenfüllung) und **14 Signale** — darunter `BTN1`–`BTN4` vollständig sowie `USB_VBUS` (3×), `USB_DP_C` (2×) und `USB_CC2`. Der Router hat zusätzlich **eine Bahn (`STAR_OUT`, B.Cu) durch das Befestigungsloch der USB-Buchse gelegt** — zwei DRC-Meldungen aus derselben Ursache. |

> **Korrektur vom 15.08.2026.** Hier stand, Top sei vollständig und Mid bis auf
> zehn Masseanbindungen geroutet. Das galt für einen Arbeitsstand, der nie im
> Repository landete: Der Umbau vom 15.08. (Reed-Kontakte, Haubenkontakt,
> Klinkenbuchse, ToF) hat die Layouts von Mid und Top **neu erzeugt** und dabei
> deren Verdrahtung verworfen — `grep -c '(segment'` zählt in beiden Boarddateien
> null. Nur das Bottom-Board trägt Leiterbahnen. Die Angaben in der Nutzen-
> Dokumentation („Mid und Top sind platziert, aber noch nicht geroutet") waren
> die richtigen.

### Freerouting 2.3.0 geprüft — und wieder verworfen

Am 17.08.2026 gegen 1.9.0 gemessen, an derselben DSN des Top-Boards, importiert
in dieselbe Ausgangsplatine, DRC mit denselben Regeln:

| | Segmente | unconnected | Verletzungen |
|---|---:|---:|---|
| **1.9.0** | 197 | **71** | 5 (davon 3 bekannt und gewollt) |
| 2.3.0 | 214 | 74 | **26** — darunter 9 `via_dangling` und 5 `track_width` |

Beeindruckend ist sie trotzdem: neun Threads statt einem, eine **Fanout-Stufe**,
die die SMD-Pads erst ausfädelt, und ein Fortschrittslog mit Score je Durchgang.
Der ganze Lauf dauerte zwei Minuten statt vierzig.

Nur taugt das Ergebnis nicht. Zwei Befunde:

1. **Sie speichert nicht ihr bestes Ergebnis.** Das Log zeigt es wörtlich: Die
   Routing-Stufe endet mit *19 unrouted*, die Optimierung startet auf einem
   Board mit *22 unrouted* und speichert genau das. Das ist derselbe Fehler,
   wegen dem schon 2.1.0 verworfen wurde — nach einem Jahr unverändert.
2. **Sie hält die Netzklassen nicht ein.** Fünf `track_width`-Verletzungen und
   neun freistehende Vias sind kein Randproblem, sondern zeigen, dass die
   Regeln aus der DSN nicht durchgesetzt werden.

Der Test bleibt reproduzierbar: `tools/freerouting.Dockerfile` nimmt
`--build-arg FREEROUTING_VERSION` und `--build-arg JRE_TAG` (2.3.0 verlangt
Java 25, 1.9.0 läuft auf 21). Wenn eine spätere Version erscheint, ist der
Vergleich eine Viertelstunde Arbeit.

### Bottom: der frische Lauf war schlechter, der alte Stand bleibt

Am 17.08.2026 wurde das Bottom-Board auf ausdrücklichen Wunsch neu geroutet,
obwohl davon abgeraten war. Das Ergebnis bestätigt den Einwand:

| | Segmente | Vias | offene Verbindungen | Kupferfehler |
|---|---:|---:|---:|---:|
| **alter Stand** | **985** | 102 | 61 | **0** |
| frischer Lauf | 835 | 89 | 78 | **602** |

Der neue Lauf ist auf jeder Achse schlechter — weniger Verdrahtung, mehr
offene Verbindungen, und 503 Abstands- plus 99 Bohrungsverletzungen, wo vorher
keine einzige war. **Der alte Stand ist wiederhergestellt** (er lag ohnehin im
Git), der neue liegt zum Nachsehen im Scratchpad.

Der Grund ist kein Zufall und kein Fehler des Containers: Der 985er-Stand ist
laut Git-Historie **das ausgewählte beste Ergebnis aus mehreren Anläufen**
(„Fortsetzungsstand übernommen", „frischer Lauf gestartet", „bester
Routing-Stand übernommen"). Ein einzelner frischer Lauf kann das nicht
zuverlässig schlagen — Freerouting ist nicht deterministisch gut.

> **Methodenfehler, der dabei fast durchgegangen wäre:** Der erste Vergleich
> maß den alten Stand als Kopie *außerhalb* seines Projektverzeichnisses. Ohne
> `.kicad_pro` fällt `kicad-cli drc` auf KiCads Standardregeln zurück — 0,2 mm
> statt der hier gültigen 0,15 mm — und meldete 508 Verletzungen für ein Board,
> das in Wahrheit keine hat. **Ein DRC-Vergleich ist nur im Projektverzeichnis
> gültig.**

### Was der Mid-Lauf gezeigt hat

Der frühere Lauf unter Linux endete mit 655 Segmenten, 73 Vias und **null**
offenen Signalverbindungen. Der Lauf vom 16.08.2026 kommt auf 746 Segmente,
104 Vias — aber 18 offene Signale und fünf Kupferfehler. Das Board ist in der
Zwischenzeit dichter geworden: 46 statt 39 Bauteile, 61 statt 57 Netze, der
Expander auf der Rückseite und vier Reed-Netzwerke statt zwei.

Die Kupferfehler sind **nicht verstreut**: Alle fünf betreffen dasselbe
Netzpaar an derselben Stelle. Das ist eine lokale Reparatur, kein neuer Lauf.

> **Der Kurzschluss bleibt bewusst im Board stehen.** Ihn automatisch
> herauszuschneiden hieße, Leiterbahnen zu löschen, ohne zu wissen welche —
> und ein stillschweigend entfernter Fehler ist schlimmer als ein sichtbarer.
> Das DRC-Gate von `gen_fab.py` verhindert, dass daraus versehentlich
> Fertigungsdaten entstehen.

### Routing auf macOS: der Container

Freerouting 1.9.0 ist keine echte Konsolenanwendung — es instanziiert
AWT-Klassen auch im Batchbetrieb und braucht deshalb ein X-Display. Unter Linux
löst das `xvfb-run`; auf macOS gibt es kein Xvfb. Dafür gibt es jetzt
[`../tools/freerouting.Dockerfile`](../tools/freerouting.Dockerfile) — eine JRE,
Xvfb und das Jar, sonst nichts:

```bash
docker build -f tools/freerouting.Dockerfile -t switchstack-freerouting tools/
python3 tools/route_boards.py mid
```

`route_boards.py` wählt selbst: Liegt ein lokales Jar **und** `xvfb-run` vor,
läuft es wie bisher direkt; sonst nimmt es den Container und schreibt die Pfade
auf dessen Sicht um. Der Rest der Pipeline — DSN-Export und SES-Import — läuft
über die `pcbnew`-API und braucht keinen Container.

**Erfahrungswerte aus der Automatisierung, die weiter gelten:**

- Freerouting 2.1.0 headless ist unbrauchbar (SES vom falschen Stand);
  1.9.0 unter `xvfb-run` funktioniert zuverlässig.
- `ZONE_FILLER` braucht ein X-Display; headless stürzt er ab.
- Ein baumelndes Bahnende verbindet sich **nie** mit einer Zone — die
  Füllung hält auch um Endkappen Abstand. Zonen verbinden nur Pads
  (Anbindungsmodus) und Vias.
- Nach `SaveBoard()` ist das Board-Objekt in der SWIG-API instabil —
  erst speichern, dann für weitere Schritte neu laden.

## 6. Erzeugte Fertigungsdaten

`python3 tools/gen_fab.py [bottom|mid|top]` erzeugt je Board Gerber
(9 Lagen), Excellon-Bohrdaten mit PDF-Karte und CSV-Positionsdatei und
packt sie nach `hardware/fab/<board>.zip` — aber **nur, wenn das DRC-Gate
besteht** (keine Kupferfehler, keine offenen Verbindungen).

**Aktuell existieren keine Fertigungsdaten.** Der frühere Export
`hardware/fab/top_ui.zip` ist am 15.08.2026 gelöscht worden: Er enthielt die um
180° verdrehte USB-C-Buchse (Punkt 39) und passte auch sonst nicht mehr zum
Board. Neue Daten entstehen erst nach dem Routing — das DRC-Gate von
`gen_fab.py` lässt nichts anderes zu.

**Die 28 `clearance`-Meldungen des Top-Boards gehören nicht dazu.** Sie sind
Pad-zu-Pad-Abstände **innerhalb** des USB-C-Footprints: 0,85 mm Rasterteilung
gegen die Vorgabe von 0,15 mm Kupferabstand. Das ist eine Regel-gegen-Footprint-
Frage (lokale Regelausnahme oder anderer Verbinder), kein Layoutfehler, und sie
bestand vor und nach der Drehungskorrektur unverändert. Was die Korrektur
tatsächlich beseitigt hat: **11 → 1** Randabstandsverletzungen. Die eine
verbliebene ist der Platzhalter-Footprint der Klinkenbuchse (Punkt 30).

Die Stücklisten aller drei Boards liegen als `bom_bottom/mid/top.csv`
neben den Schaltplänen — erzeugt aus derselben Quelle wie die Schaltpläne
selbst (`tools/gen_*_sch.py`).

## Fertigungsnutzen

Die drei Platinen werden als **ein Nutzen** bestellt:
[`../hardware/fab/panel/`](../hardware/fab/panel/README.md), erzeugt mit
`tools/gen_panel.py`. **173,4 × 64,4 mm = 112 cm²**, gemischte Geometrie: zwei
Kreise Ø 52 (Bottom, Mid) und ein abgerundetes Quadrat 47 × 47 (Top). Je vier
Stege von 4 mm mit fünf Mausbissen — am Kreis auf den Diagonalen, am Quadrat je
einer pro Kante, um 10 mm aus der Kantenmitte versetzt. Mittig wäre dort
entweder eine Befestigungsbohrung oder der überstehende Klinken-Platzhalter.

Der Nutzen ist ein **Build-Ergebnis**, keine Quelle. Die drei Projekte unter
`hardware/` bleiben führend und einzeln revidierbar; erst im Nutzen bekommen
Referenzen (`B_`, `M_`, `T_`) und Netze (`BOT_`, `MID_`, `TOP_`) ein Präfix,
weil beides dort eindeutig sein muss. Die Designregeln werden aus den drei
Quellprojekten übernommen, sonst meldet KiCad die 0,15-mm-Leiterbahnen des
Bottom-Boards gegen seine 0,2-mm-Vorgabe als Fehler.

**Nach dem Ausbrechen ist jede Platine am Steg zu verputzen** — der Grat steht
rund 0,5 mm über, und in der Dose stehen nur 1,5–2,5 mm Luft zur Verfügung.

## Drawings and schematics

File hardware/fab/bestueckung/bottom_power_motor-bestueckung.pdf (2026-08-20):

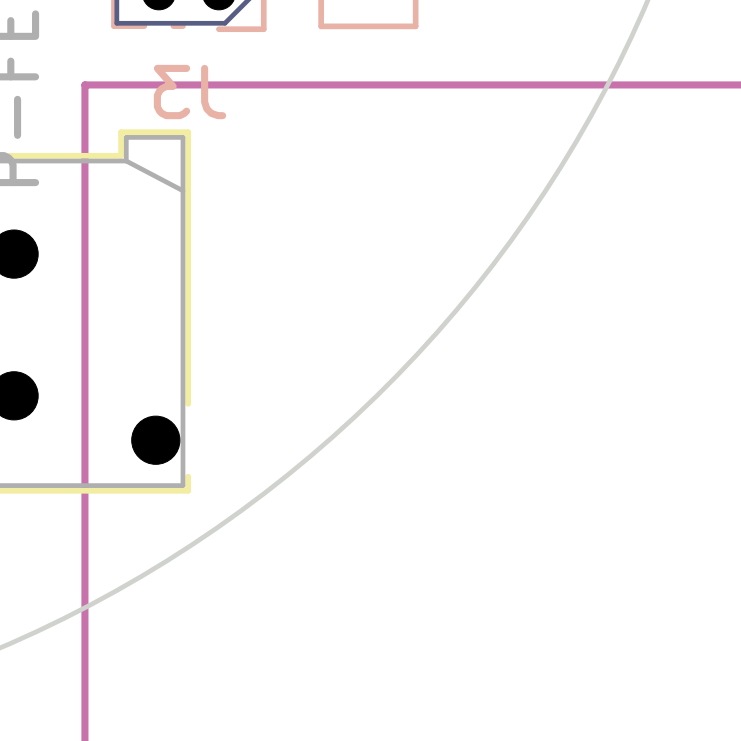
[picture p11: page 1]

Size: A4 | Rev:
KiCad E.D.A. 10.0.5 | Id: 1/1

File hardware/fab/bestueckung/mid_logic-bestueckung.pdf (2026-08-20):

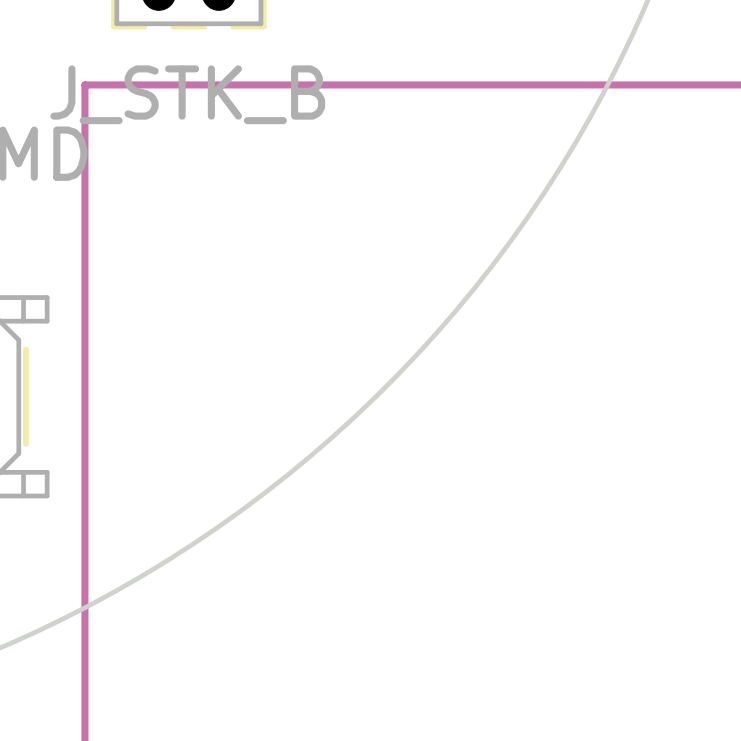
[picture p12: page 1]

Size: A4 | Rev:
KiCad E.D.A. 10.0.5 | Id: 1/1

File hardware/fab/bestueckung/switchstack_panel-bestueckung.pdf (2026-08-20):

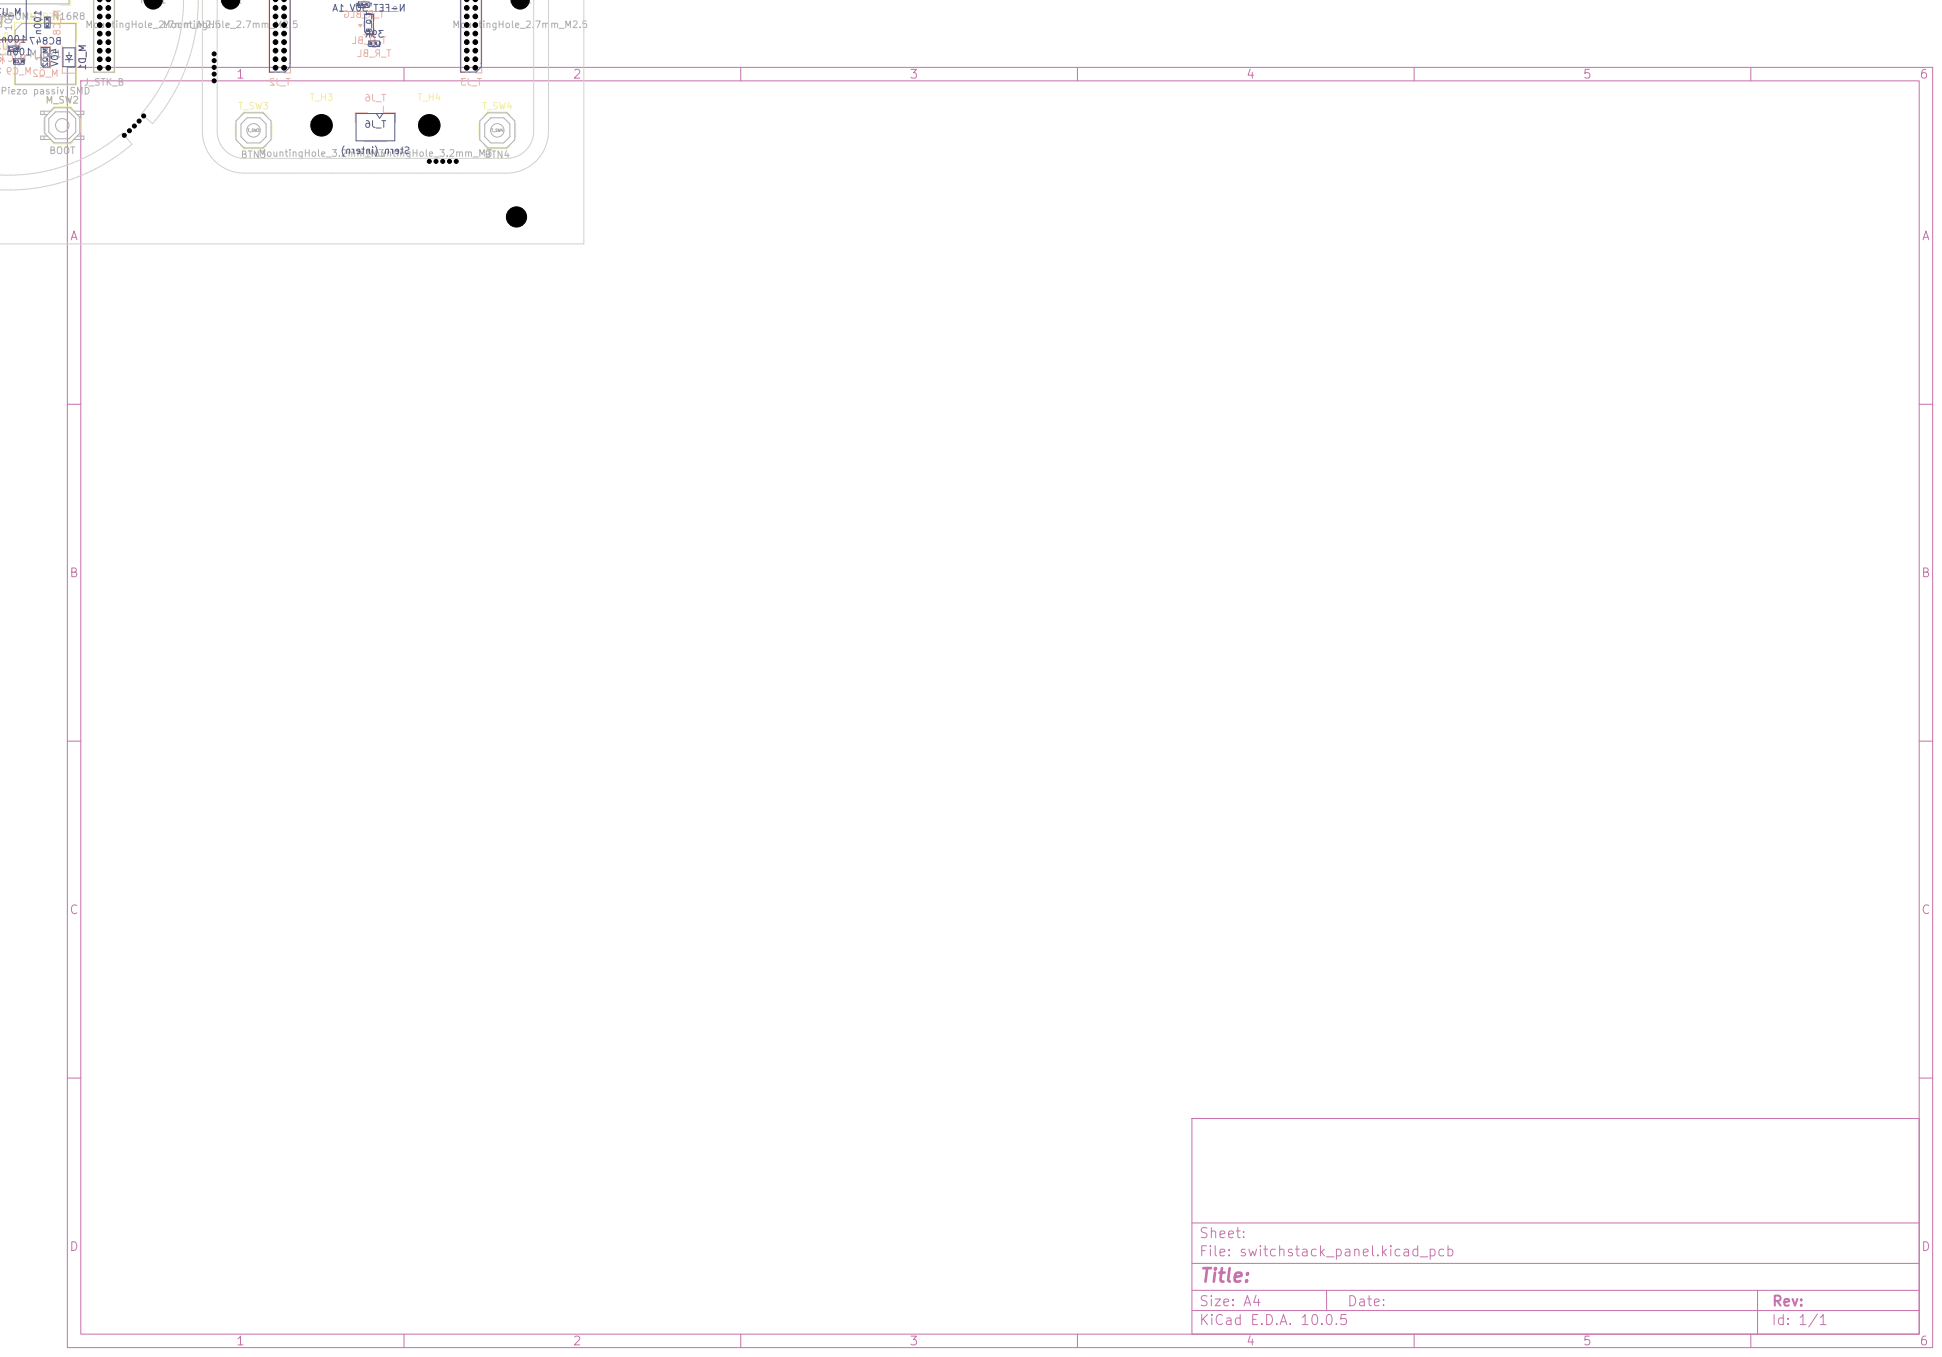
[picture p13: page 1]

Size: A4 | Rev:
KiCad E.D.A. 10.0.5 | Id: 1/1

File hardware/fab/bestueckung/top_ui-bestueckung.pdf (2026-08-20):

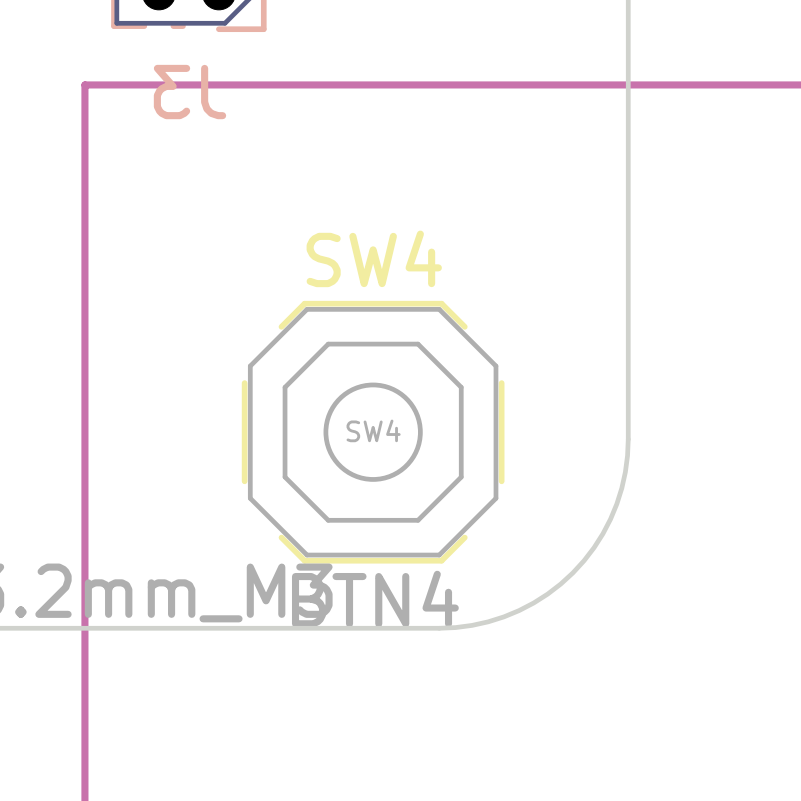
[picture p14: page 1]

Size: A4 | Rev:
KiCad E.D.A. 10.0.5 | Id: 1/1

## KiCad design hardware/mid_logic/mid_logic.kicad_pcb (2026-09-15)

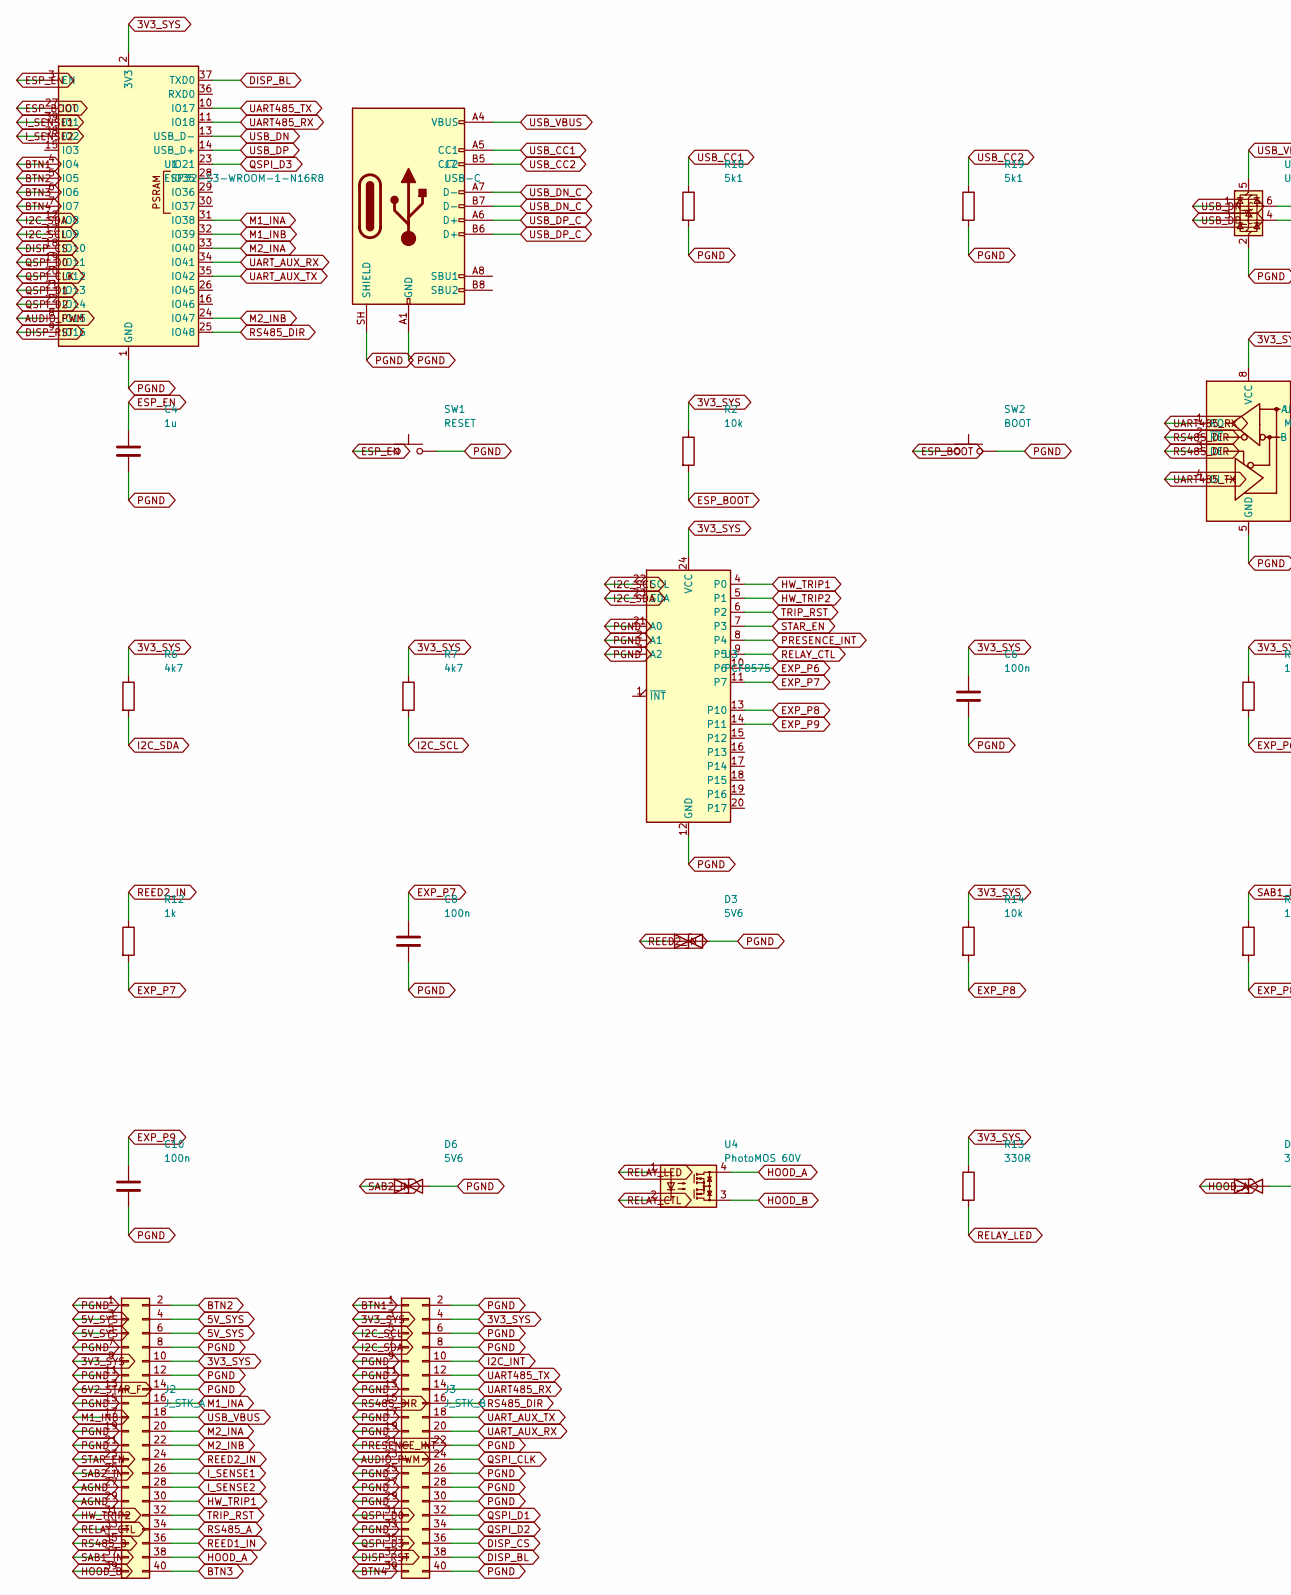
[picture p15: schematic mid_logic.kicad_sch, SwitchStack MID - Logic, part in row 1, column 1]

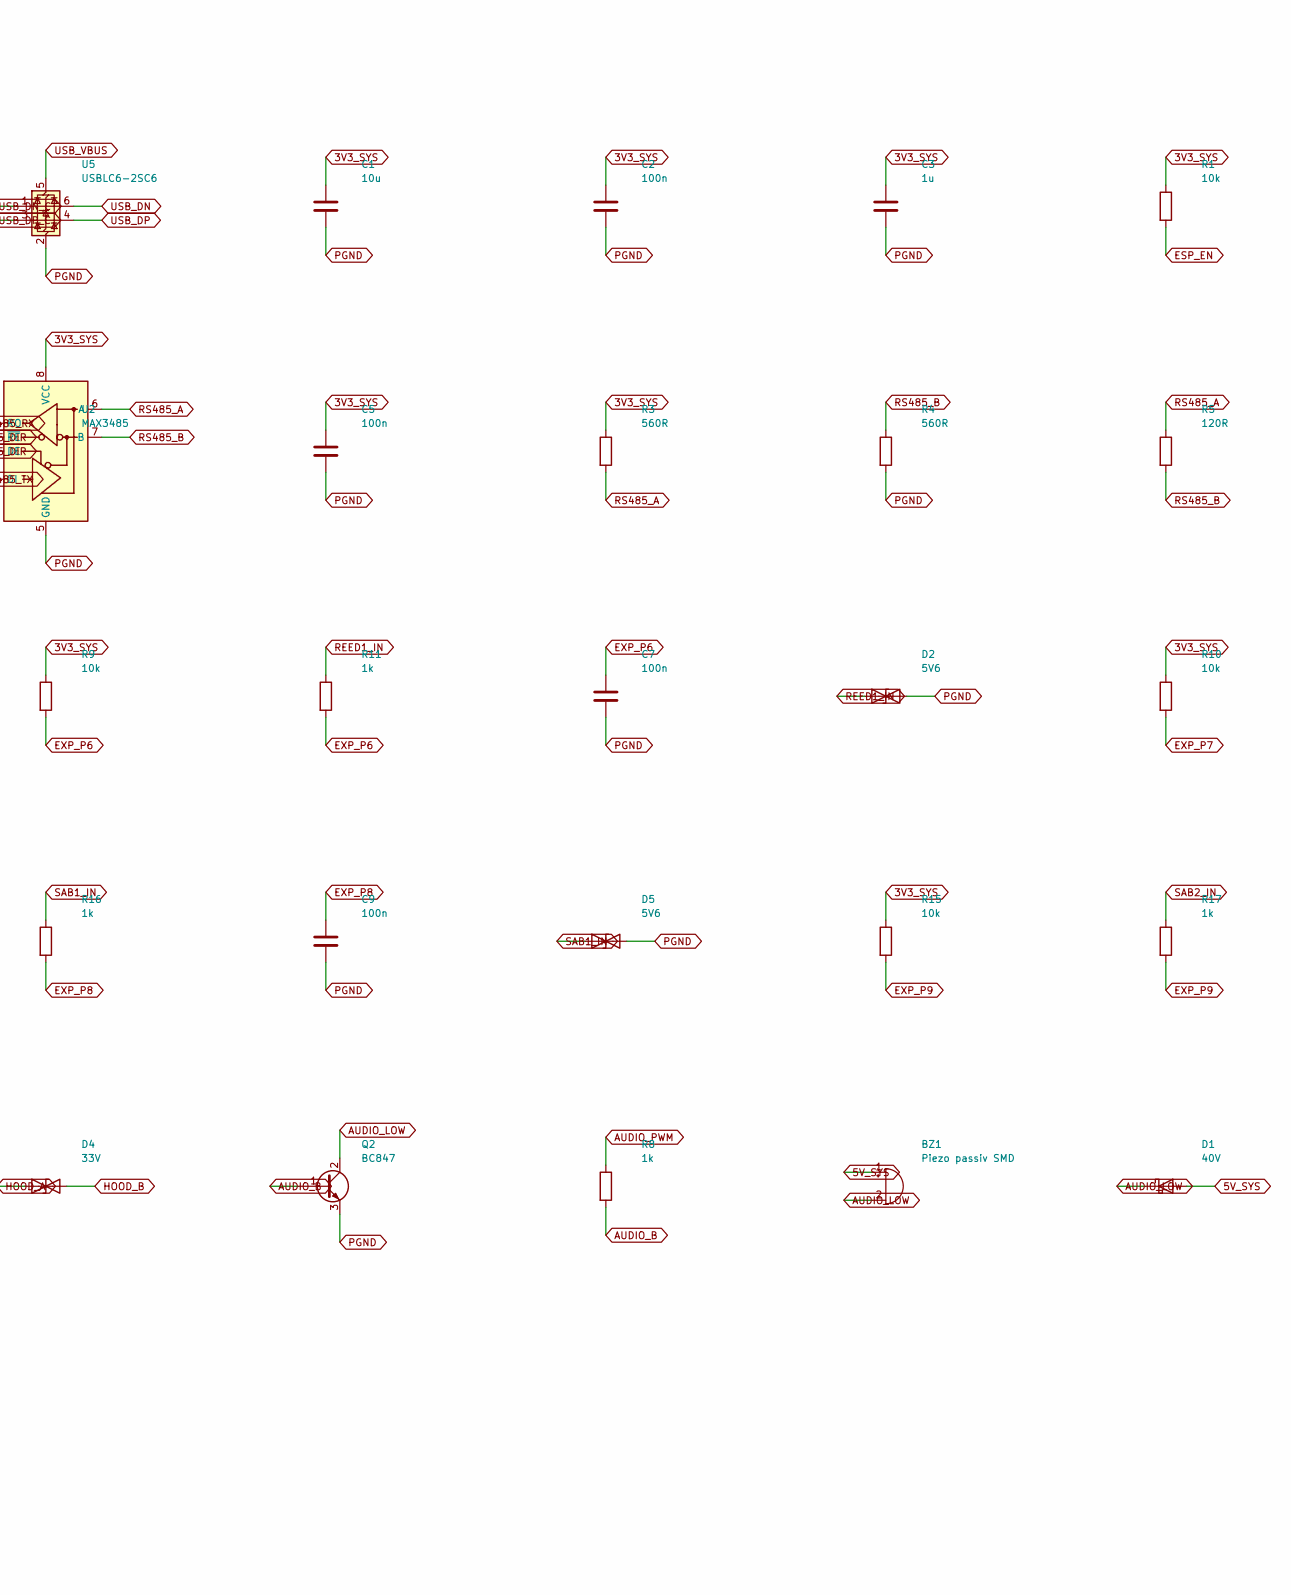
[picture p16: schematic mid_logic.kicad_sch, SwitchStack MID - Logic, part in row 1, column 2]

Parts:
BZ1: Piezo passiv SMD; Buzzer_Murata_PKMCS0909E; MPN Murata PKMCS0909E o.ae., 9 x 9 x 3 mm S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
C1: 10u; C_0805_2012Metric
C2, C5, C6, C7, C8, C9, C10: 100n; C_0603_1608Metric
C3, C4: 1u; C_0603_1608Metric
D1: 40V; D_SOD-123
D2, D3, D5, D6: 5V6; D_SOD-123; MPN ESD am Feldstecker
D4: 33V; D_SOD-123; MPN Klemmung am Haubenausgang
J2: J_STK_A; PinHeader_2x20_P1.27mm_Vertical_Durchsteck
J3: J_STK_B; PinHeader_2x20_P1.27mm_Vertical_Durchsteck
J7: USB-C; USB_C_Receptacle_G-Switch_GT-USB-7051x; MPN G-Switch GT-USB-7051A/B, vertikal SMT (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
Q2: BC847; SOT-23
R1, R2: 10k; R_0603_1608Metric
R3: 560R; R_0603_1608Metric; MPN Fail-Safe-Bias A
R4: 560R; R_0603_1608Metric; MPN Fail-Safe-Bias B
R5: 120R; R_0603_1608Metric; MPN DNP - nur bestuecken, wenn dieses Gerae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
R6, R7: 4k7; R_0603_1608Metric
R8: 1k; R_0603_1608Metric
R9: 10k; R_0603_1608Metric; MPN Pullup Reed 1
R10: 10k; R_0603_1608Metric; MPN Pullup Reed 2
R11: 1k; R_0603_1608Metric; MPN Serie Reed 1
R12: 1k; R_0603_1608Metric; MPN Serie Reed 2
R13: 330R; R_0603_1608Metric; MPN LED-Strom PhotoMOS, ca. 6 mA
R14: 10k; R_0603_1608Metric; MPN Pullup Reed 3
R15: 10k; R_0603_1608Metric; MPN Pullup Reed 4
R16: 1k; R_0603_1608Metric; MPN Serie Reed 3
R17: 1k; R_0603_1608Metric; MPN Serie Reed 4
R18, R19: 5k1; R_0603_1608Metric
SW1: RESET; SW_SPST_TL3342
SW2: BOOT; SW_SPST_TL3342
U1: ESP32-S3-WROOM-1-N16R8; ESP32-S3-WROOM-1; MPN Antenne zeigt zur Front (+Y), Keepout a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
U2: MAX3485; SOIC-8_3.9x4.9mm_P1.27mm; MPN 3,3-V-Typ; Pinbelegung gegen Datenblatt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
U3: PCF8575; SSOP-24_5.3x8.2mm_P0.65mm; MPN Adresse 0x20: A0=A1=A2=GND - muss zur Y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
U4: PhotoMOS 60V; SOP-4_4.4x2.6mm_P1.27mm; MPN 1 Form A, SELV - NICHT fuer Netzspannung
U5: USBLC6-2SC6; SOT-23-6

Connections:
3V3_SYS: C1.1, C2.1, C3.1, C5.1, C6.1, J2.9, J2.10, J3.3, J3.4, R1.1, R2.1, R3.1, R6.1, R7.1, R9.1, R10.1, R13.1, R14.1, R15.1, U1.2 (3V3), U2.8 (VCC), U3.24 (VCC)
5V_SYS: BZ1.1 (+), D1.2 (A), J2.3, J2.4, J2.5, J2.6
6V2_STAR_F: J2.13
AGND: J2.27, J2.29
AUDIO_B: Q2.1 (B), R8.2
AUDIO_LOW: BZ1.2 (-), D1.1 (K), Q2.2 (C)
AUDIO_PWM: J3.23, R8.1, U1.8 (IO15)
BTN1: J3.1, U1.4 (IO4)
BTN2: J2.2, U1.5 (IO5)
BTN3: J2.40, U1.6 (IO6)
BTN4: J3.39, U1.7 (IO7)
DISP_BL: J3.38, U1.37 (TXD0)
DISP_CS: J3.36, U1.18 (IO10)
DISP_RST: J3.37, U1.9 (IO16)
ESP_BOOT: R2.2, SW2.1, U1.27 (IO0)
ESP_EN: C4.1, R1.2, SW1.1, U1.3 (EN)
EXP_P6: C7.1, R9.2, R11.2, U3.10 (P6)
EXP_P7: C8.1, R10.2, R12.2, U3.11 (P7)
EXP_P8: C9.1, R14.2, R16.2, U3.13 (P10)
EXP_P9: C10.1, R15.2, R17.2, U3.14 (P11)
HOOD_A: D4.1 (A1), J2.38, U4.4
HOOD_B: D4.2 (A2), J2.39, U4.3
HW_TRIP1: J2.30, U3.4 (P0)
HW_TRIP2: J2.31, U3.5 (P1)
I2C_INT: J3.10
I2C_SCL: J3.5, R7.2, U1.17 (IO9), U3.22 (SCL)
I2C_SDA: J3.7, R6.2, U1.12 (IO8), U3.23 (SDA)
I_SENSE1: J2.26, U1.39 (IO1)
I_SENSE2: J2.28, U1.38 (IO2)
M1_INA: J2.16, U1.31 (IO38)
M1_INB: J2.17, U1.32 (IO39)
M2_INA: J2.20, U1.33 (IO40)
M2_INB: J2.22, U1.24 (IO47)
PRESENCE_INT: J3.21, U3.8 (P4)
QSPI_CLK: J3.24, U1.20 (IO12)
QSPI_D0: J3.31, U1.19 (IO11)
QSPI_D1: J3.32, U1.21 (IO13)
QSPI_D2: J3.34, U1.22 (IO14)
QSPI_D3: J3.35, U1.23 (IO21)
REED1_IN: D2.1 (A1), J2.36, R11.1
REED2_IN: D3.1 (A1), J2.24, R12.1
RELAY_CTL: J2.33, U3.9 (P5), U4.2
RELAY_LED: R13.2, U4.1
RS485_A: J2.34, R3.2, R5.1, U2.6 (A)
RS485_B: J2.35, R4.1, R5.2, U2.7 (B)
RS485_DIR: J3.15, J3.16, U1.25 (IO48), U2.2 (~RE), U2.3 (DE)
SAB1_IN: D5.1 (A1), J2.37, R16.1
SAB2_IN: D6.1 (A1), J2.25, R17.1
STAR_EN: J2.23, U3.7 (P3)
TRIP_RST: J2.32, U3.6 (P2)
UART485_RX: J3.14, U1.11 (IO18), U2.1 (RO)
UART485_TX: J3.12, U1.10 (IO17), U2.4 (DI)
UART_AUX_RX: J3.20, U1.34 (IO41)
UART_AUX_TX: J3.18, U1.35 (IO42)
USB_CC1: J7.A5 (CC1), R18.1
USB_CC2: J7.B5 (CC2), R19.1
USB_DN: U1.13 (USB_D-), U5.6 (I/O1)
USB_DN_C: J7.A7 (D-), J7.B7 (D-), U5.1 (I/O1)
USB_DP: U1.14 (USB_D+), U5.4 (I/O2)
USB_DP_C: J7.A6 (D+), J7.B6 (D+), U5.3 (I/O2)
USB_VBUS: J2.18, J7.A4 (VBUS), J7.A9 (VBUS), J7.B4 (VBUS), J7.B9 (VBUS), U5.5 (VBUS)

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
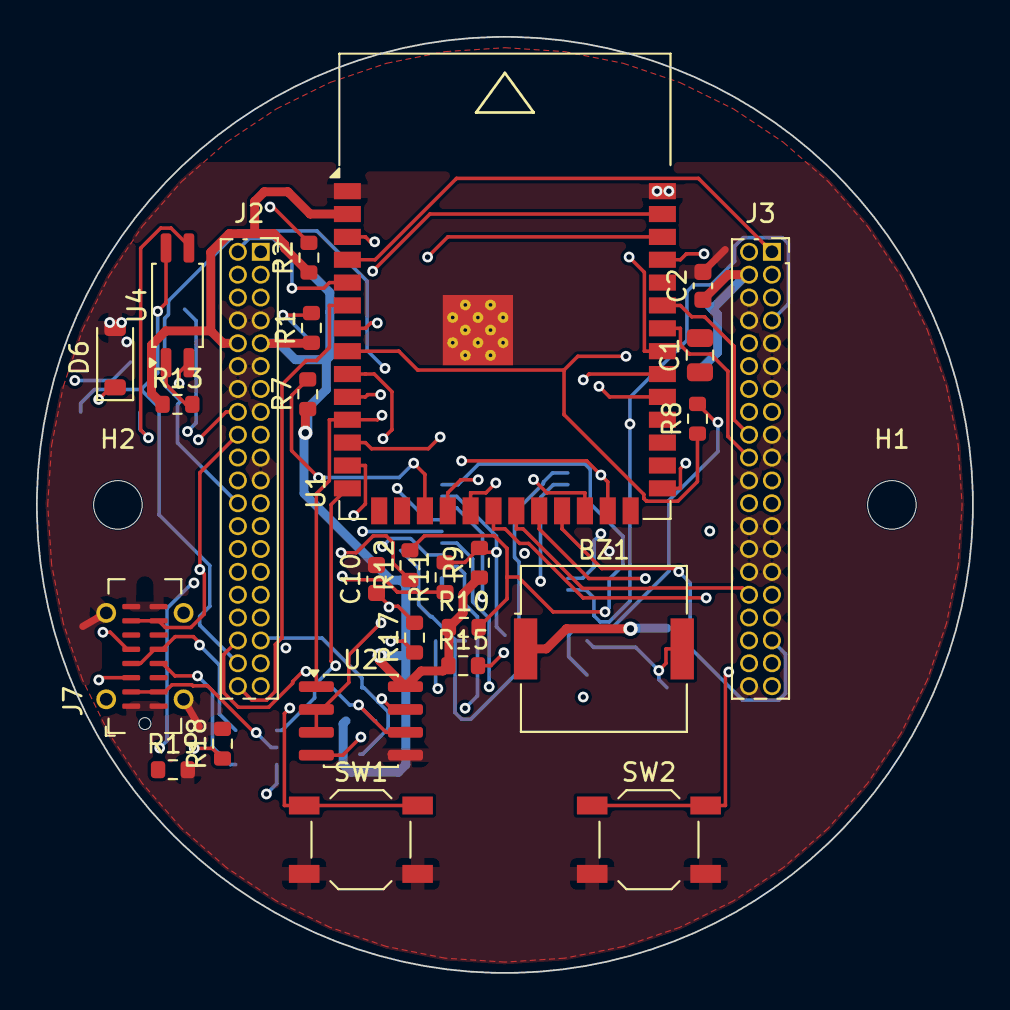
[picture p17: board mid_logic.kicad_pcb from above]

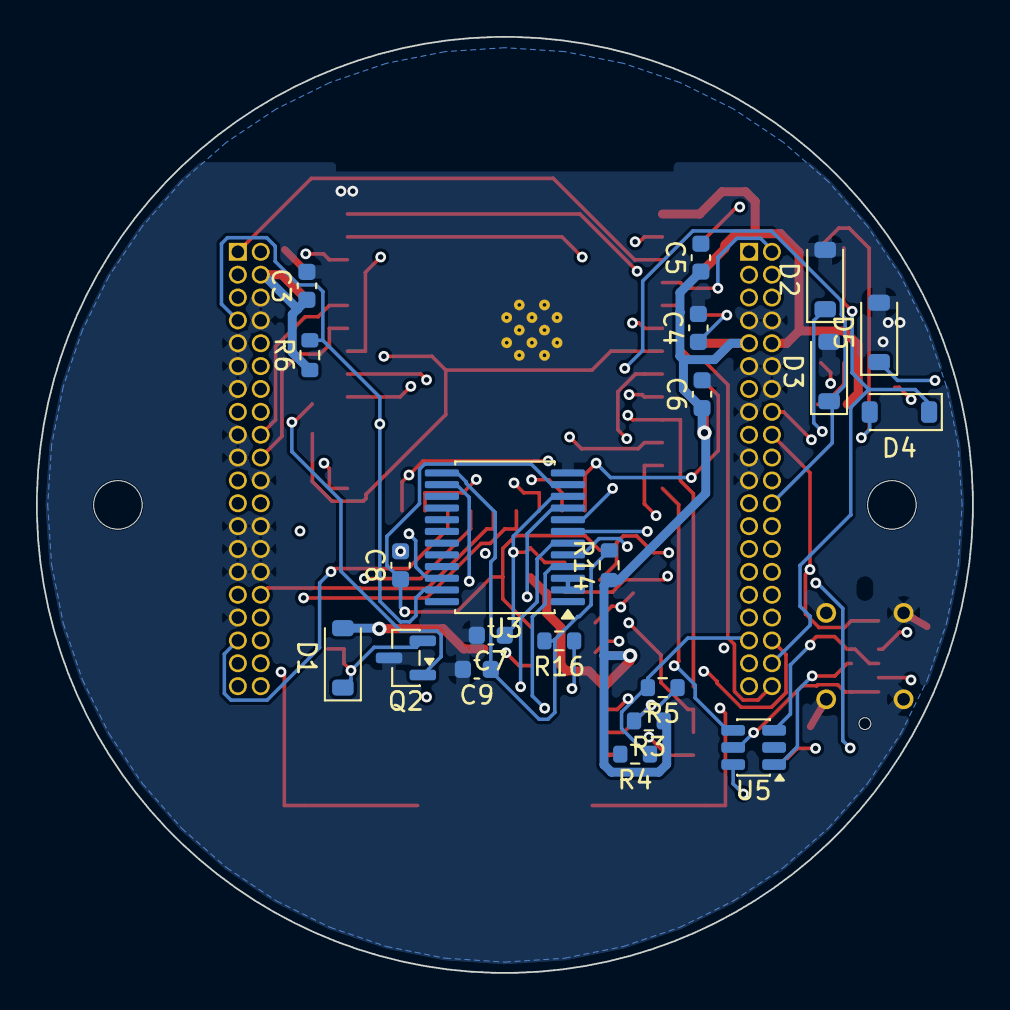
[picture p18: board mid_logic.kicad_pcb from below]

Board: 4 copper layers, 52.0 x 52.0 mm, 49 parts (21 on the bottom side), 60 nets.

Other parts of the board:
H1, H2: MountingHole_2.7mm_M2.5

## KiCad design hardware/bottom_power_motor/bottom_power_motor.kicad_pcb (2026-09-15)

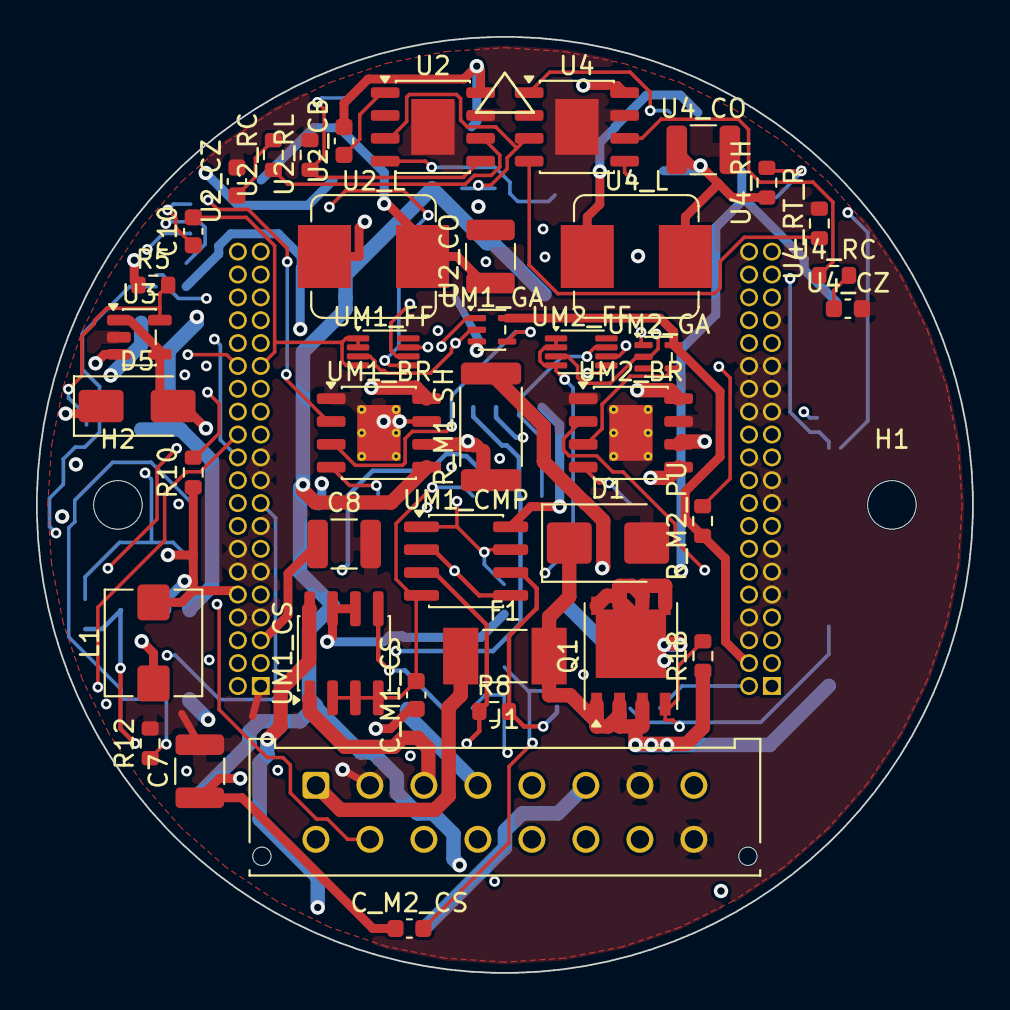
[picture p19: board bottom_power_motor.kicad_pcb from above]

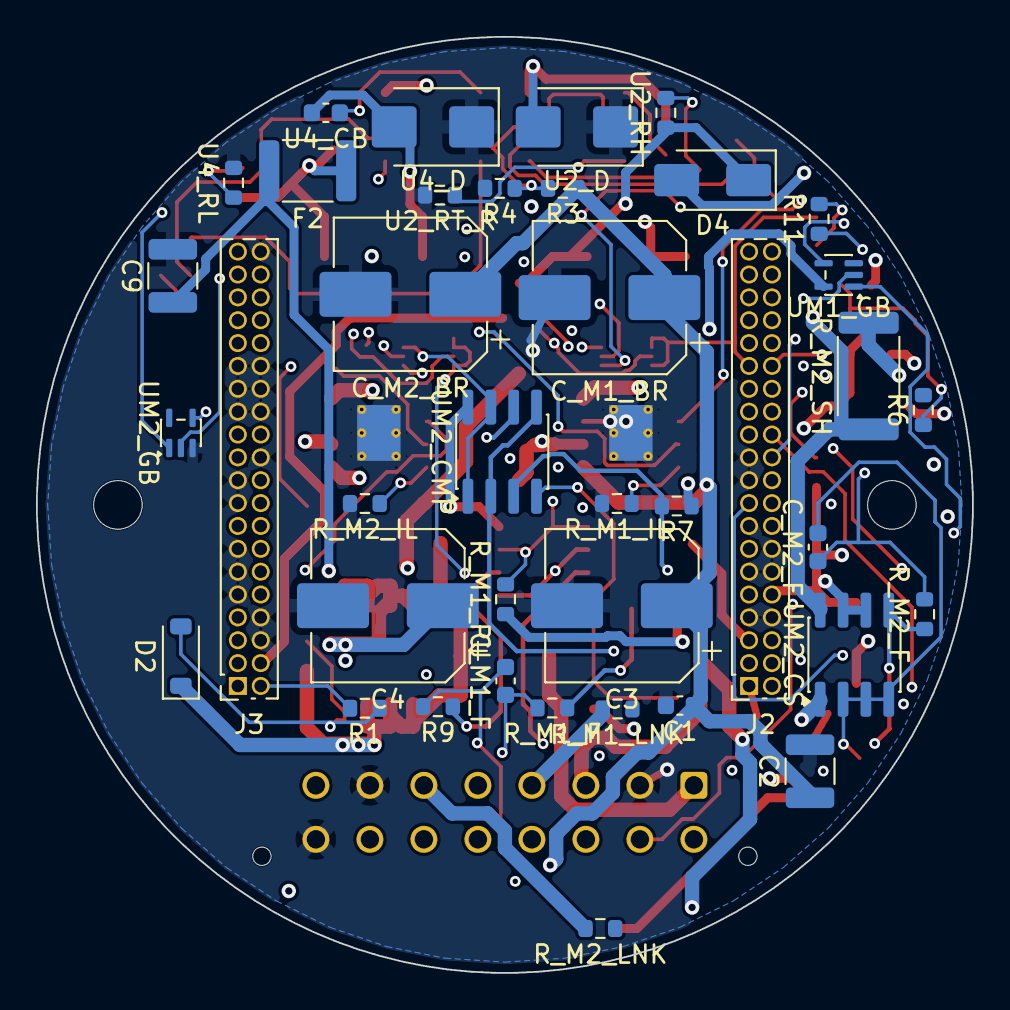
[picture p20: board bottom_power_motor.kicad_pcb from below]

Board: 4 copper layers, 52.0 x 52.0 mm, 82 parts (39 on the bottom side), 67 nets.

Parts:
C1, C10: 100n; C_0603_1608Metric
C2: 10u; C_1210_3225Metric
C3, C4: 220u/35V Polymer; CP_Elec_8x6.5
C7, C8, C9: 22u; C_1210_3225Metric
C_M1_BR, C_M2_BR: 100u/35V Polymer; CP_Elec_8x6.5
C_M1_CS, C_M2_CS: 100n; C_0603_1608Metric
C_M1_F, C_M2_F: 1n; C_0603_1608Metric
D1: SMBJ30A; D_SMB
D2: 12V; D_SOD-123
D4, D5: 40V 3A; D_SMA
F1: 15A flink; Fuse_Littelfuse-NANO2-451_453
F2: 0.5A; Fuse_1812_4532Metric
H1, H2: MountingHole_2.7mm_M2.5
J1: Feld 16p; Molex_Micro-Fit_3.0_43045-1612_2x08_P3.00mm_Vertical
J2: J_STK_A; PinSocket_2x20_P1.27mm_Vertical
J3: J_STK_B; PinSocket_2x20_P1.27mm_Vertical
L1: 2u2; L_Bourns_SRP5030T
Q1: P-FET 40V 30A; PowerPAK_SO-8_Single
R1, R10: 100k; R_0603_1608Metric
R1B: 1M; R_0603_1608Metric
R3: 392k; R_0603_1608Metric
R4: 88k7; R_0603_1608Metric
R5: 180k; R_0603_1608Metric
R6, R8: 40k2; R_0603_1608Metric
R7, R9: 10k0; R_0603_1608Metric
R11: 1k; R_0603_1608Metric
R12: 0R; R_0603_1608Metric
R_M1_F, R_M2_F: 1k; R_0603_1608Metric
R_M1_IL, R_M2_IL: 33k0; R_0603_1608Metric
R_M1_LNK, R_M2_LNK: 0R; R_0603_1608Metric
R_M1_PU, R_M2_PU: 10k; R_0603_1608Metric
R_M1_SH, R_M2_SH: 5m0 1W; R_2512_6332Metric
U2, U4: TPS54360; HSOP-8-1EP_3.9x4.9mm_P1.27mm_EP2.41x3.1mm
U2_CB, U4_CB: 100n; C_0603_1608Metric
U2_CO: 47u; C_1210_3225Metric
U2_CZ, U4_CZ: 3n3; C_0603_1608Metric
U2_D, U4_D: 60V 3A; D_SMB
U2_L: 10u; L_Bourns_SRP7028A_7.3x6.6mm
U2_RC, U4_RC: 10k; R_0603_1608Metric
U2_RH: 53k6; R_0603_1608Metric
U2_RL: 10k2; R_0603_1608Metric
U2_RT_R, U4_RT_R: 100k; R_0603_1608Metric
U3: TLV62569; SOT-23-5
U4_CO: 22u; C_1210_3225Metric
U4_L: 33u; L_Bourns_SRP7028A_7.3x6.6mm
U4_RH: 68k1; R_0603_1608Metric
U4_RL: 10k0; R_0603_1608Metric
UM1_BR, UM2_BR: DRV8871; HSOP-8-1EP_3.9x4.9mm_P1.27mm_EP2.41x3.1mm_ThermalVias
UM1_CMP, UM2_CMP: TLV3702; SOIC-8_3.9x4.9mm_P1.27mm
UM1_CS, UM2_CS: INA240A2; SOIC-8_3.9x4.9mm_P1.27mm
UM1_FF, UM2_FF: 74AUP1G74; VSSOP-8_2.3x2mm_P0.5mm
UM1_GA, UM1_GB, UM2_GA, UM2_GB: 74AHC1G08; SOT-353_SC-70-5

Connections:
3V3_SYS: C7.1, C_M1_CS.1, C_M2_CS.1, J2.9, J2.10, J3.3, J3.4, L1.2, R5.1, R7.1, R10.1, R_M1_PU.1, R_M2_PU.1, UM1_CMP.8, UM1_CS.6, UM1_CS.7, UM1_FF.8, UM1_GA.5, UM1_GB.5, UM2_CMP.8, UM2_CS.6, UM2_CS.7, UM2_FF.8, UM2_GA.5, UM2_GB.5
5V_BUCK: D4.1, U2_CO.1, U2_L.2, U2_RH.1
5V_SYS: C8.1, D4.2, D5.2, J2.3, J2.4, J2.5, J2.6, U3.1, U3.4
6V2_STAR: F2.1, U4_CO.1, U4_L.2, U4_RH.1
6V2_STAR_F: C9.1, F2.2, J2.13
24V_EN: R3.2, R4.1, U2.3, U4.3
24V_F: D1.1, D2.1, F1.2, Q1.1, Q1.2, Q1.3, R1B.1
24V_GATE_P: D2.2, Q1.4, R1.1, R1B.2
24V_IN: F1.1, J1.1
24V_PROT: C1.1, C2.1, C3.1, C4.1, C_M1_BR.1, C_M2_BR.1, Q1.5, R3.1, U2.2, U4.2, UM1_BR.5, UM2_BR.5
AGND: C10.2, C_M1_CS.2, C_M1_F.2, C_M2_CS.2, C_M2_F.2, J2.27, J2.29, R9.2, R12.1, UM1_CMP.4, UM1_CS.2, UM1_CS.3, UM1_CS.4, UM1_FF.1, UM1_FF.2, UM1_FF.4, UM2_CMP.4, UM2_CS.2, UM2_CS.3, UM2_CS.4, UM2_FF.1, UM2_FF.2, UM2_FF.4
EN_LOOP: J3.2, R1.2
HOOD_A: J1.14, J2.38
HOOD_B: J1.15, J2.39
HW_TRIP1: J2.30, UM1_FF.5
HW_TRIP2: J2.31, UM2_FF.5
I_SENSE1: C_M1_F.1, J2.26, R_M1_F.2
I_SENSE2: C_M2_F.1, J2.28, R_M2_F.2
M1_A: J1.3, R_M1_SH.2, UM1_CS.1
M1_B: J1.4, R_M1_LNK.2, UM1_BR.8
M1_GA: UM1_BR.3, UM1_GA.4
M1_GB: UM1_BR.2, UM1_GB.4
M1_ILIM: R_M1_IL.1, UM1_BR.4
M1_INA: J2.16, UM1_GA.1
M1_INB: J2.17, UM1_GB.1
M1_ISNS: R_M1_F.1, UM1_CMP.2, UM1_CMP.5, UM1_CS.5
M1_SD: UM1_FF.3, UM1_GA.2, UM1_GB.2
M1_SWA: R_M1_SH.1, UM1_BR.6, UM1_CS.8
M1_TRIP: R_M1_PU.2, UM1_CMP.1, UM1_CMP.7, UM1_FF.7
M2_A: J1.5, R_M2_SH.2, UM2_CS.1
M2_B: J1.6, R_M2_LNK.2, UM2_BR.8
M2_GA: UM2_BR.3, UM2_GA.4
M2_GB: UM2_BR.2, UM2_GB.4
M2_ILIM: R_M2_IL.1, UM2_BR.4
M2_INA: J2.20, UM2_GA.1
M2_INB: J2.22, UM2_GB.1
M2_ISNS: R_M2_F.1, UM2_CMP.2, UM2_CMP.5, UM2_CS.5
M2_SD: UM2_FF.3, UM2_GA.2, UM2_GB.2
M2_SWA: R_M2_SH.1, UM2_BR.6, UM2_CS.8
M2_TRIP: R_M2_PU.2, UM2_CMP.1, UM2_CMP.7, UM2_FF.7
PGND: C1.2, C2.2, C3.2, C4.2, C7.2, C8.2, C9.2, C_M1_BR.2, C_M2_BR.2, D1.2, J1.2, J1.7, J1.16, J2.1, J2.7, J2.8, J2.11, J2.12, J2.14, J2.15, J2.19, J2.21, J3.6, J3.8, J3.9, J3.11, J3.13, J3.17, J3.19, J3.22, J3.25, J3.26, J3.27, J3.28, J3.29, J3.30, J3.33, J3.40, R4.2, R6.2, R12.2, R_M1_IL.2, R_M2_IL.2, U2.7, U2.9, U2_CO.2, U2_CZ.2, U2_D.1, U2_RL.2, U2_RT_R.2, U3.2, U4.7, U4.9, U4_CO.2, U4_CZ.2, U4_D.1, U4_RL.2, U4_RT_R.2, UM1_BR.1, UM1_BR.7, UM1_BR.9, UM1_GA.3, UM1_GB.3, UM2_BR.1, UM2_BR.7, UM2_BR.9, UM2_GA.3, UM2_GB.3
REED1_IN: J1.10, J2.36
REED2_IN: J1.12, J2.24
RS485_A: J1.8, J2.34
RS485_B: J1.9, J2.35
RS485_DIR: J3.15, J3.16
SAB1_IN: J1.11, J2.37
SAB2_IN: J1.13, J2.25
TRIP_CLR: C10.1, R10.2, R11.2, UM1_FF.6, UM2_FF.6
TRIP_RST: J2.32, R11.1
U2_BOOT: U2.1, U2_CB.1
U2_COMP: U2.6, U2_RC.1
U2_CZ_N: U2_CZ.1, U2_RC.2
U2_FB: U2.5, U2_RH.2, U2_RL.1
U2_RT: U2.4, U2_RT_R.1
U2_SW: U2.8, U2_CB.2, U2_D.2, U2_L.1
U3_FB: R5.2, R6.1, U3.5
U3_SW: L1.1, U3.3
U4_BOOT: U4.1, U4_CB.1
U4_COMP: U4.6, U4_RC.1
U4_CZ_N: U4_CZ.1, U4_RC.2
U4_FB: U4.5, U4_RH.2, U4_RL.1
U4_RT: U4.4, U4_RT_R.1
U4_SW: U4.8, U4_CB.2, U4_D.2, U4_L.1
USB_VBUS: D5.1, J2.18
V_TRIP_HI: R7.2, R8.1, UM1_CMP.3, UM2_CMP.3
V_TRIP_LO: R8.2, R9.1, UM1_CMP.6, UM2_CMP.6

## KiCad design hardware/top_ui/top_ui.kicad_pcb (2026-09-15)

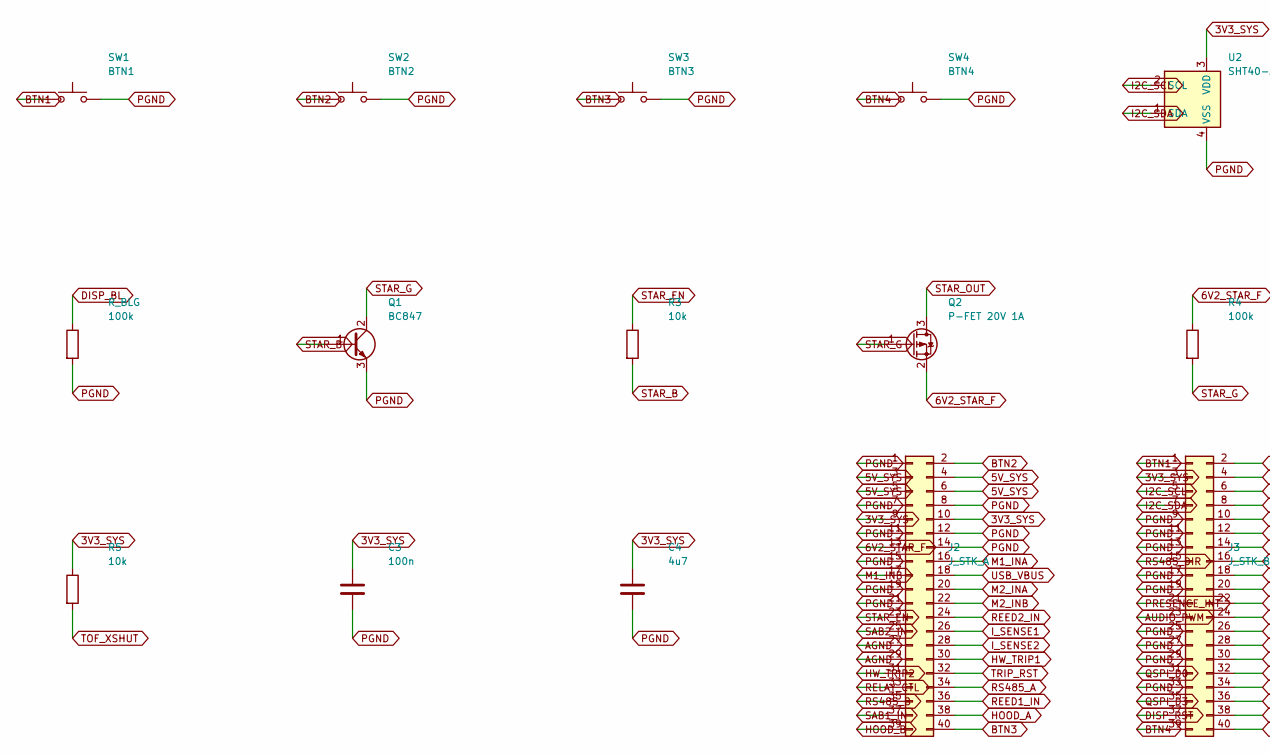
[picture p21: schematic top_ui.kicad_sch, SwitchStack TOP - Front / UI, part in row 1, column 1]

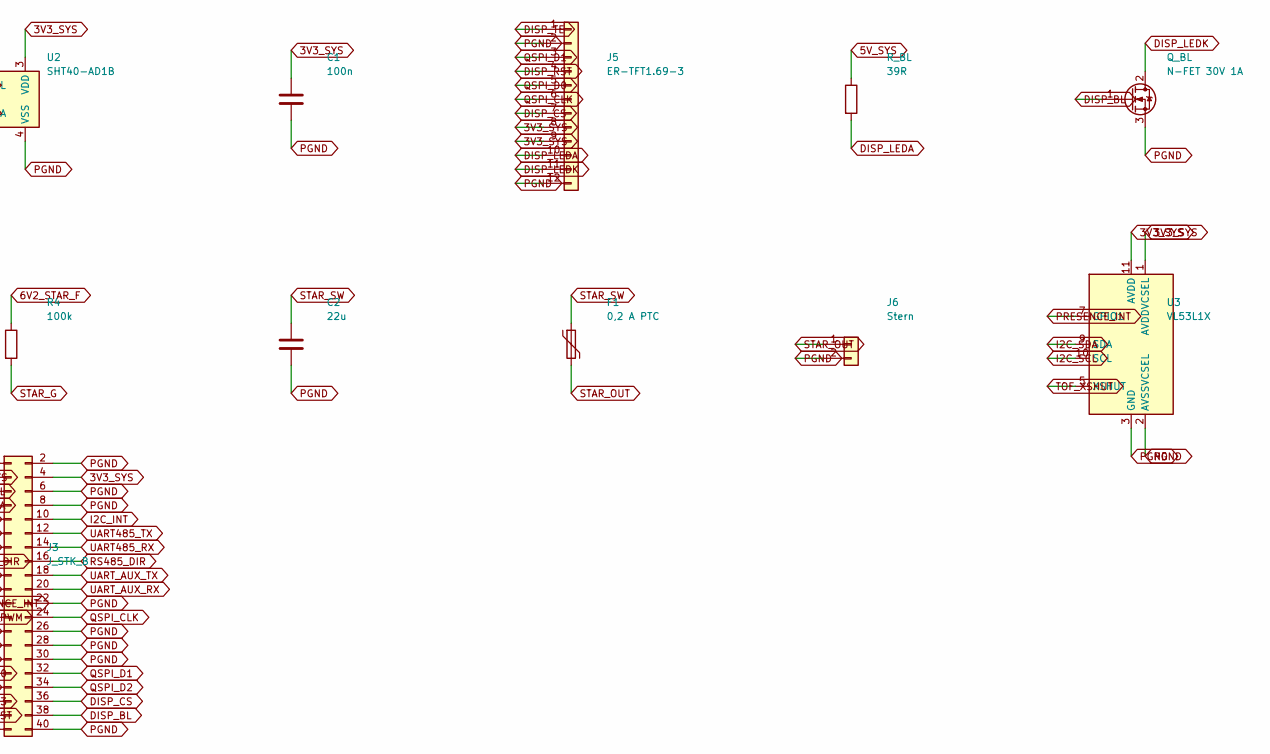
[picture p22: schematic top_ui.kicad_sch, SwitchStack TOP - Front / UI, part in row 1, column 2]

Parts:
C1, C3: 100n; C_0603_1608Metric
C2: 22u; C_1210_3225Metric
C4: 4u7; C_0603_1608Metric
F1: 0,2 A PTC; Fuse_1206_3216Metric; MPN Haltestrom > 100 mA, Ausloesestrom < 40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
J2: J_STK_A; PinSocket_2x20_P1.27mm_Vertical
J3: J_STK_B; PinSocket_2x20_P1.27mm_Vertical
J5: ER-TFT1.69-3; TE_1-1734839-2_1x12-1MP_P0.5mm_Horizontal; MPN Panel ER-TFT1.69-3, 12-pol FPC 0,50 mm 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
J6: Stern; JST_GH_BM02B-GHS-TBT_1x02-1MP_P1.25mm_Vertical; MPN JST GH BM02B-GHS-TBT, 2-polig stehend m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
Q1: BC847; SOT-23
Q2: P-FET 20V 1A; SOT-23; MPN z.B. AO3401 - 80 mA Last, unkritisch
Q_BL: N-FET 30V 1A; SOT-23; MPN Logic-Level, Vgs(th) < 2 V - 2N7002 rei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
R3: 10k; R_0603_1608Metric
R4: 100k; R_0603_1608Metric; MPN Gate-Pull-up: aus ohne Ansteuerung
R5: 10k; R_0603_1608Metric; MPN XSHUT-Pullup: Sensor immer aktiv
R_BL: 39R; R_0603_1608Metric; MPN Vorwiderstand Hintergrundbeleuchtung, 8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
R_BLG: 100k; R_0603_1608Metric; MPN Gate-Pulldown: Beleuchtung aus, solange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
SW1: BTN1; SW_Push_SPST_NO_Alps_SKRK; MPN Alps SKRK o.ae., 3,9x2,9 - Ecke oben re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
SW2: BTN2; SW_Push_SPST_NO_Alps_SKRK; MPN Alps SKRK o.ae., 3,9x2,9 - Ecke oben li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
SW3: BTN3; SW_Push_SPST_NO_Alps_SKRK; MPN Alps SKRK o.ae., 3,9x2,9 - Ecke unten l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
SW4: BTN4; SW_Push_SPST_NO_Alps_SKRK; MPN Alps SKRK o.ae., 3,9x2,9 - Ecke unten r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
U2: SHT40-AD1B; Sensirion_DFN-4_1.5x1.5mm_P0.8mm_SHT4x_NoCentralPad; MPN Adresse 0x44 - muss zur YAML passen; th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
U3: VL53L1X; ST_VL53L1x; MPN Optikfenster freihalten, Uebersprechen: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

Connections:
3V3_SYS: C1.1, C3.1, C4.1, J2.9, J2.10, J3.3, J3.4, J5.8, J5.9, R5.1, U2.3 (VDD), U3.1 (AVDDVCSEL), U3.11 (AVDD)
5V_SYS: J2.3, J2.4, J2.5, J2.6, R_BL.1
6V2_STAR_F: J2.13, Q2.2 (S), R4.1
AGND: J2.27, J2.29
AUDIO_PWM: J3.23
BTN1: J3.1, SW1.1
BTN2: J2.2, SW2.1
BTN3: J2.40, SW3.1
BTN4: J3.39, SW4.1
DISP_BL: J3.38, Q_BL.1 (G), R_BLG.1
DISP_CS: J3.36, J5.7
DISP_LEDA: J5.10, R_BL.2
DISP_LEDK: J5.11, Q_BL.2 (D)
DISP_RST: J3.37, J5.4
DISP_TE: J5.1
HOOD_A: J2.38
HOOD_B: J2.39
HW_TRIP1: J2.30
HW_TRIP2: J2.31
I2C_INT: J3.10
I2C_SCL: J3.5, U2.2 (SCL), U3.10 (SCL)
I2C_SDA: J3.7, U2.1 (SDA), U3.9 (SDA)
I_SENSE1: J2.26
I_SENSE2: J2.28
M1_INA: J2.16
M1_INB: J2.17
M2_INA: J2.20
M2_INB: J2.22
PRESENCE_INT: J3.21, U3.7 (GPIO1)
QSPI_CLK: J3.24, J5.6
QSPI_D0: J3.31, J5.5
QSPI_D1: J3.32, J5.3
QSPI_D2: J3.34
QSPI_D3: J3.35
REED1_IN: J2.36
REED2_IN: J2.24
RELAY_CTL: J2.33
RS485_A: J2.34
RS485_B: J2.35
RS485_DIR: J3.15, J3.16
SAB1_IN: J2.37
SAB2_IN: J2.25
STAR_B: Q1.1 (B), R3.2
STAR_EN: J2.23, R3.1
STAR_G: Q1.2 (C), Q2.1 (G), R4.2
STAR_OUT: F1.2, J6.1, Q2.3 (D)
STAR_SW: C2.1, F1.1
TOF_XSHUT: R5.2, U3.5 (XSHUT)
TRIP_RST: J2.32
UART485_RX: J3.14
UART485_TX: J3.12
UART_AUX_RX: J3.20
UART_AUX_TX: J3.18
USB_VBUS: J2.18

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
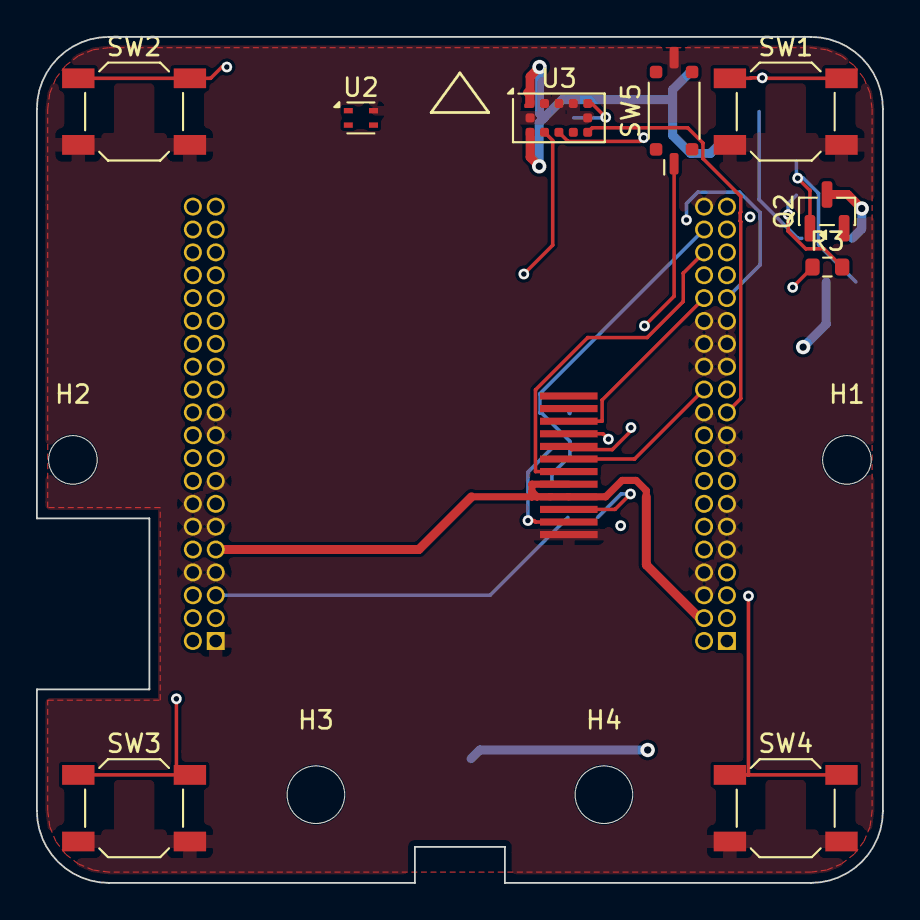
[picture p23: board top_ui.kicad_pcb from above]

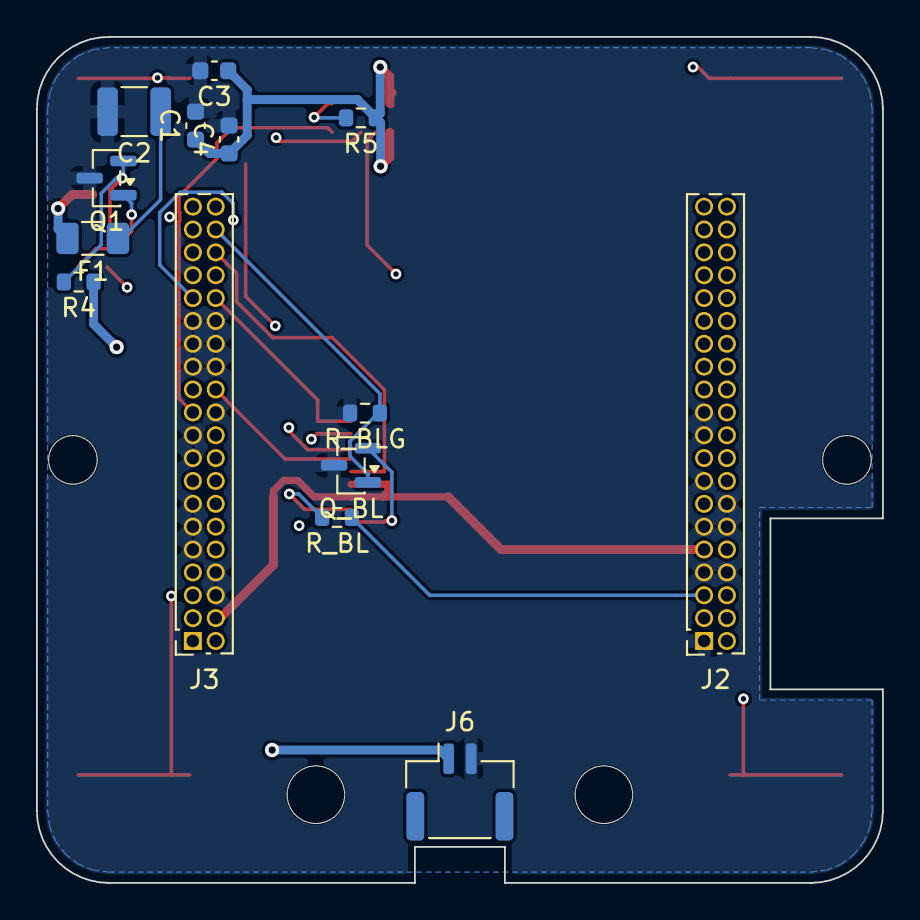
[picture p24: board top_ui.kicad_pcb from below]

Board: 4 copper layers, 47.0 x 47.0 mm, 28 parts (14 on the bottom side), 28 nets.

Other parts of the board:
H1, H2: MountingHole_2.7mm_M2.5
H3, H4: MountingHole_3.2mm_M3
SW5: HAUPT; SW_DIP_SPSTx01_Slide_Copal_CVS-01xB_W5.9mm_P1mm

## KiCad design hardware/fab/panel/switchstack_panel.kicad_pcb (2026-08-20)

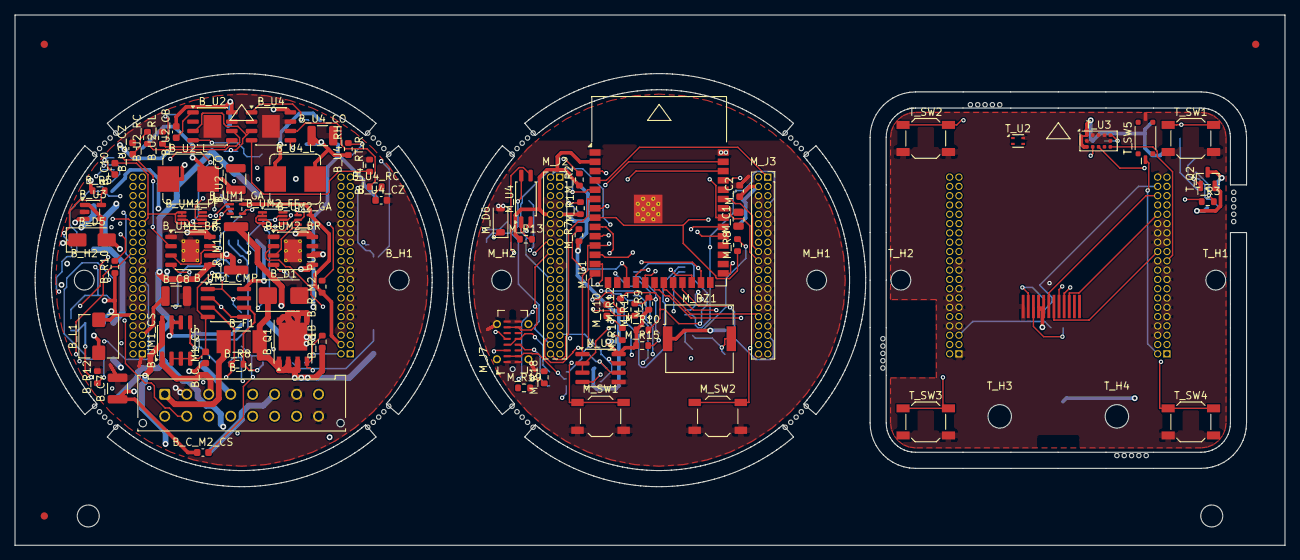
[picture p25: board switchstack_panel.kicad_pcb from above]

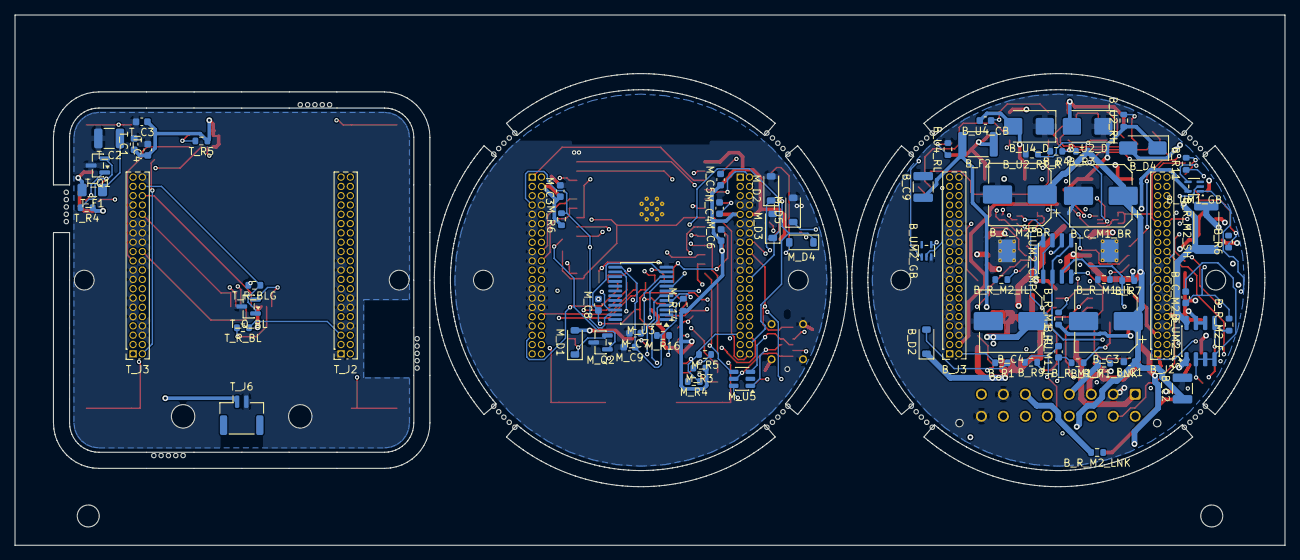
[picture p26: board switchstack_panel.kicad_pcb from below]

Board: 4 copper layers, 173.4 x 72.4 mm, 224 parts (74 on the bottom side), 155 nets.

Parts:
B_C1, B_C10: 100n; C_0603_1608Metric
B_C2: 10u; C_1210_3225Metric
B_C3, B_C4: 220u/35V Polymer; CP_Elec_8x6.5
B_C7, B_C8, B_C9: 22u; C_1210_3225Metric
B_C_M1_BR, B_C_M2_BR: 100u/35V Polymer; CP_Elec_8x6.5
B_C_M1_CS, B_C_M2_CS: 100n; C_0603_1608Metric
B_C_M1_F, B_C_M2_F: 1n; C_0603_1608Metric
B_D1: SMBJ30A; D_SMB
B_D2: 12V; D_SOD-123
B_D4, B_D5: 40V 3A; D_SMA
B_F1: 15A flink; Fuse_Littelfuse-NANO2-451_453
B_F2: 0.5A; Fuse_1812_4532Metric
B_H1, B_H2: MountingHole_2.7mm_M2.5
B_J1: Feld 16p; Molex_Micro-Fit_3.0_43045-1612_2x08_P3.00mm_Vertical
B_J2: J_STK_A; PinSocket_2x20_P1.27mm_Vertical
B_J3: J_STK_B; PinSocket_2x20_P1.27mm_Vertical
B_L1: 2u2; L_Bourns_SRP5030T
B_Q1: P-FET 40V 30A; PowerPAK_SO-8_Single
B_R1, B_R10: 100k; R_0603_1608Metric
B_R1B: 1M; R_0603_1608Metric
B_R3: 392k; R_0603_1608Metric
B_R4: 88k7; R_0603_1608Metric
B_R5: 180k; R_0603_1608Metric
B_R6, B_R8: 40k2; R_0603_1608Metric
B_R7, B_R9: 10k0; R_0603_1608Metric
B_R11: 1k; R_0603_1608Metric
B_R12: 0R; R_0603_1608Metric
B_R_M1_F, B_R_M2_F: 1k; R_0603_1608Metric
B_R_M1_IL, B_R_M2_IL: 33k0; R_0603_1608Metric
B_R_M1_LNK, B_R_M2_LNK: 0R; R_0603_1608Metric
B_R_M1_PU, B_R_M2_PU: 10k; R_0603_1608Metric
B_R_M1_SH, B_R_M2_SH: 5m0 1W; R_2512_6332Metric
B_U2, B_U4: TPS54360; HSOP-8-1EP_3.9x4.9mm_P1.27mm_EP2.41x3.1mm
B_U2_CB, B_U4_CB: 100n; C_0603_1608Metric
B_U2_CO: 47u; C_1210_3225Metric
B_U2_CZ, B_U4_CZ: 3n3; C_0603_1608Metric
B_U2_D, B_U4_D: 60V 3A; D_SMB
B_U2_L: 10u; L_Bourns_SRP7028A_7.3x6.6mm
B_U2_RC, B_U4_RC: 10k; R_0603_1608Metric
B_U2_RH: 53k6; R_0603_1608Metric
B_U2_RL: 10k2; R_0603_1608Metric
B_U2_RT_R, B_U4_RT_R: 100k; R_0603_1608Metric
B_U3: TLV62569; SOT-23-5
B_U4_CO: 22u; C_1210_3225Metric
B_U4_L: 33u; L_Bourns_SRP7028A_7.3x6.6mm
B_U4_RH: 68k1; R_0603_1608Metric
B_U4_RL: 10k0; R_0603_1608Metric
B_UM1_BR, B_UM2_BR: DRV8871; HSOP-8-1EP_3.9x4.9mm_P1.27mm_EP2.41x3.1mm_ThermalVias
B_UM1_CMP, B_UM2_CMP: TLV3702; SOIC-8_3.9x4.9mm_P1.27mm
B_UM1_CS, B_UM2_CS: INA240A2; SOIC-8_3.9x4.9mm_P1.27mm
B_UM1_FF, B_UM2_FF: 74AUP1G74; VSSOP-8_2.3x2mm_P0.5mm
B_UM1_GA, B_UM1_GB, B_UM2_GA, B_UM2_GB: 74AHC1G08; SOT-353_SC-70-5
FID: (no value)
FID#2, FID#3: (no value)
MB: (no value)
MB#2, MB#3, MB#4, MB#5, MB#6, MB#7, MB#8, MB#9, MB#10, MB#11, MB#12, MB#13, MB#14, MB#15, MB#16, MB#17, MB#18, MB#19, MB#20, MB#21, MB#22, MB#23, MB#24, MB#25, MB#26, MB#27, MB#28, MB#29, MB#30, MB#31, MB#32, MB#33, MB#34, MB#35, MB#36, MB#37, MB#38, MB#39, MB#40, MB#41, MB#42, MB#43, MB#44, MB#45, MB#46, MB#47, MB#48, MB#49, MB#50, MB#51, MB#52, MB#53, MB#54, MB#55, MB#56, MB#57, MB#58, MB#59, MB#60: (no value)
M_BZ1: Piezo passiv SMD; Buzzer_Murata_PKMCS0909E
M_C1: 10u; C_0805_2012Metric
M_C2, M_C5, M_C6, M_C7, M_C8, M_C9, M_C10: 100n; C_0603_1608Metric
M_C3, M_C4: 1u; C_0603_1608Metric
M_D1: 40V; D_SOD-123
M_D2, M_D3, M_D5, M_D6: 5V6; D_SOD-123
M_D4: 33V; D_SOD-123
M_H1, M_H2: MountingHole_2.7mm_M2.5
M_J2: J_STK_A; PinSocket_2x20_P1.27mm_Vertical
M_J3: J_STK_B; PinSocket_2x20_P1.27mm_Vertical
M_J7: USB-C; USB_C_Receptacle_G-Switch_GT-USB-7051x
M_Q2: BC847; SOT-23
M_R1, M_R2, M_R9, M_R10, M_R14, M_R15: 10k; R_0603_1608Metric
M_R3, M_R4: 560R; R_0603_1608Metric
M_R5: 120R; R_0603_1608Metric
M_R6, M_R7: 4k7; R_0603_1608Metric
M_R8, M_R11, M_R12, M_R16, M_R17: 1k; R_0603_1608Metric
M_R13: 330R; R_0603_1608Metric
M_R18, M_R19: 5k1; R_0603_1608Metric
M_SW1: RESET; SW_SPST_TL3342
M_SW2: BOOT; SW_SPST_TL3342
M_U1: ESP32-S3-WROOM-1-N16R8; ESP32-S3-WROOM-1
M_U2: MAX3485; SOIC-8_3.9x4.9mm_P1.27mm
M_U3: PCF8575; SSOP-24_5.3x8.2mm_P0.65mm
M_U4: PhotoMOS 60V; SOP-4_4.4x2.6mm_P1.27mm
M_U5: USBLC6-2SC6; SOT-23-6
TOOL: (no value)
TOOL#2: (no value)
T_C1, T_C3: 100n; C_0603_1608Metric
T_C2: 22u; C_1210_3225Metric
T_C4: 4u7; C_0603_1608Metric
T_F1: 0,2 A PTC; Fuse_1206_3216Metric
T_H1, T_H2: MountingHole_2.7mm_M2.5
T_H3, T_H4: MountingHole_3.2mm_M3
T_J2: J_STK_A; PinSocket_2x20_P1.27mm_Vertical
T_J3: J_STK_B; PinSocket_2x20_P1.27mm_Vertical
T_J5: ER-TFT1.69-3; FPC_Loetfeld_12x0.7mm
T_J6: Stern (intern); JST_GH_SM02B-GHS-TB_1x02-1MP_P1.25mm_Horizontal
T_Q1: BC847; SOT-23
T_Q2: P-FET 20V 1A; SOT-23
T_Q_BL: N-FET 30V 1A; SOT-23
T_R3, T_R5: 10k; R_0603_1608Metric
T_R4: 100k; R_0603_1608Metric
T_R_BL: 39R; R_0603_1608Metric
T_R_BLG: 100k; R_0603_1608Metric
T_SW1: BTN1; SW_SPST_SKQG_WithStem
T_SW2: BTN2; SW_SPST_SKQG_WithStem
T_SW3: BTN3; SW_SPST_SKQG_WithStem
T_SW4: BTN4; SW_SPST_SKQG_WithStem
T_SW5: HAUPT; SW_DIP_SPSTx01_Slide_Copal_CVS-01xB_W5.9mm_P1mm
T_U2: SHT40-AD1B; Sensirion_DFN-4_1.5x1.5mm_P0.8mm_SHT4x_NoCentralPad
T_U3: VL53L1X; ST_VL53L1x

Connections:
BOT_3V3_SYS: B_C7.1, B_C_M1_CS.1, B_C_M2_CS.1, B_J2.9, B_J2.10, B_J3.3, B_J3.4, B_L1.2, B_R5.1, B_R7.1, B_R10.1, B_R_M1_PU.1, B_R_M2_PU.1, B_UM1_CMP.8, B_UM1_CS.6, B_UM1_CS.7, B_UM1_FF.8, B_UM1_GA.5, B_UM1_GB.5, B_UM2_CMP.8, B_UM2_CS.6, B_UM2_CS.7, B_UM2_FF.8, B_UM2_GA.5, B_UM2_GB.5
BOT_5V_BUCK: B_D4.1, B_U2_CO.1, B_U2_L.2, B_U2_RH.1
BOT_5V_SYS: B_C8.1, B_D4.2, B_D5.2, B_J2.3, B_J2.4, B_J2.5, B_J2.6, B_U3.1, B_U3.4
BOT_6V2_STAR: B_F2.1, B_U4_CO.1, B_U4_L.2, B_U4_RH.1
BOT_6V2_STAR_F: B_C9.1, B_F2.2, B_J2.13
BOT_24V_EN: B_R3.2, B_R4.1, B_U2.3, B_U4.3
BOT_24V_F: B_D1.1, B_D2.1, B_F1.2, B_Q1.1, B_Q1.2, B_Q1.3, B_R1B.1
BOT_24V_GATE_P: B_D2.2, B_Q1.4, B_R1.1, B_R1B.2
BOT_24V_IN: B_F1.1, B_J1.1
BOT_24V_PROT: B_C1.1, B_C2.1, B_C3.1, B_C4.1, B_C_M1_BR.1, B_C_M2_BR.1, B_Q1.5, B_R3.1, B_U2.2, B_U4.2, B_UM1_BR.5, B_UM2_BR.5
BOT_AGND: B_C10.2, B_C_M1_CS.2, B_C_M1_F.2, B_C_M2_CS.2, B_C_M2_F.2, B_J2.27, B_J2.29, B_R9.2, B_R12.1, B_UM1_CMP.4, B_UM1_CS.2, B_UM1_CS.3, B_UM1_CS.4, B_UM1_FF.1, B_UM1_FF.2, B_UM1_FF.4, B_UM2_CMP.4, B_UM2_CS.2, B_UM2_CS.3, B_UM2_CS.4, B_UM2_FF.1, B_UM2_FF.2, B_UM2_FF.4
BOT_EN_LOOP: B_J3.2, B_R1.2
BOT_HOOD_A: B_J1.14, B_J2.38
BOT_HOOD_B: B_J1.15, B_J2.39
BOT_HW_TRIP1: B_J2.30, B_UM1_FF.5
BOT_HW_TRIP2: B_J2.31, B_UM2_FF.5
BOT_I_SENSE1: B_C_M1_F.1, B_J2.26, B_R_M1_F.2
BOT_I_SENSE2: B_C_M2_F.1, B_J2.28, B_R_M2_F.2
BOT_M1_A: B_J1.3, B_R_M1_SH.2, B_UM1_CS.1
BOT_M1_B: B_J1.4, B_R_M1_LNK.2, B_UM1_BR.8
BOT_M1_GA: B_UM1_BR.3, B_UM1_GA.4
BOT_M1_GB: B_UM1_BR.2, B_UM1_GB.4
BOT_M1_ILIM: B_R_M1_IL.1, B_UM1_BR.4
BOT_M1_INA: B_J2.16, B_UM1_GA.1
BOT_M1_INB: B_J2.17, B_UM1_GB.1
BOT_M1_ISNS: B_R_M1_F.1, B_UM1_CMP.2, B_UM1_CMP.5, B_UM1_CS.5
BOT_M1_SD: B_UM1_FF.3, B_UM1_GA.2, B_UM1_GB.2
BOT_M1_SWA: B_R_M1_SH.1, B_UM1_BR.6, B_UM1_CS.8
BOT_M1_TRIP: B_R_M1_PU.2, B_UM1_CMP.1, B_UM1_CMP.7, B_UM1_FF.7
BOT_M2_A: B_J1.5, B_R_M2_SH.2, B_UM2_CS.1
BOT_M2_B: B_J1.6, B_R_M2_LNK.2, B_UM2_BR.8
BOT_M2_GA: B_UM2_BR.3, B_UM2_GA.4
BOT_M2_GB: B_UM2_BR.2, B_UM2_GB.4
BOT_M2_ILIM: B_R_M2_IL.1, B_UM2_BR.4
BOT_M2_INA: B_J2.20, B_UM2_GA.1
BOT_M2_INB: B_J2.22, B_UM2_GB.1
BOT_M2_ISNS: B_R_M2_F.1, B_UM2_CMP.2, B_UM2_CMP.5, B_UM2_CS.5
BOT_M2_SD: B_UM2_FF.3, B_UM2_GA.2, B_UM2_GB.2
BOT_M2_SWA: B_R_M2_SH.1, B_UM2_BR.6, B_UM2_CS.8
BOT_M2_TRIP: B_R_M2_PU.2, B_UM2_CMP.1, B_UM2_CMP.7, B_UM2_FF.7
BOT_PGND: B_C1.2, B_C2.2, B_C3.2, B_C4.2, B_C7.2, B_C8.2, B_C9.2, B_C_M1_BR.2, B_C_M2_BR.2, B_D1.2, B_J1.2, B_J1.7, B_J1.16, B_J2.1, B_J2.7, B_J2.8, B_J2.11, B_J2.12, B_J2.14, B_J2.15, B_J2.19, B_J2.21, B_J3.6, B_J3.8, B_J3.9, B_J3.11, B_J3.13, B_J3.17, B_J3.19, B_J3.22, B_J3.25, B_J3.26, B_J3.27, B_J3.28, B_J3.29, B_J3.30, B_J3.33, B_J3.40, B_R4.2, B_R6.2, B_R12.2, B_R_M1_IL.2, B_R_M2_IL.2, B_U2.7, B_U2.9, B_U2_CO.2, B_U2_CZ.2, B_U2_D.1, B_U2_RL.2, B_U2_RT_R.2, B_U3.2, B_U4.7, B_U4.9, B_U4_CO.2, B_U4_CZ.2, B_U4_D.1, B_U4_RL.2, B_U4_RT_R.2, B_UM1_BR.1, B_UM1_BR.7, B_UM1_BR.9, B_UM1_GA.3, B_UM1_GB.3, B_UM2_BR.1, B_UM2_BR.7, B_UM2_BR.9, B_UM2_GA.3, B_UM2_GB.3
BOT_REED1_IN: B_J1.10, B_J2.36
BOT_REED2_IN: B_J1.12, B_J2.24
BOT_RS485_A: B_J1.8, B_J2.34
BOT_RS485_B: B_J1.9, B_J2.35
BOT_RS485_DIR: B_J3.15, B_J3.16
BOT_SAB1_IN: B_J1.11, B_J2.37
BOT_SAB2_IN: B_J1.13, B_J2.25
BOT_TRIP_CLR: B_C10.1, B_R10.2, B_R11.2, B_UM1_FF.6, B_UM2_FF.6
BOT_TRIP_RST: B_J2.32, B_R11.1
BOT_U2_BOOT: B_U2.1, B_U2_CB.1
BOT_U2_COMP: B_U2.6, B_U2_RC.1
BOT_U2_CZ_N: B_U2_CZ.1, B_U2_RC.2
BOT_U2_FB: B_U2.5, B_U2_RH.2, B_U2_RL.1
BOT_U2_RT: B_U2.4, B_U2_RT_R.1
BOT_U2_SW: B_U2.8, B_U2_CB.2, B_U2_D.2, B_U2_L.1
BOT_U3_FB: B_R5.2, B_R6.1, B_U3.5
BOT_U3_SW: B_L1.1, B_U3.3
BOT_U4_BOOT: B_U4.1, B_U4_CB.1
BOT_U4_COMP: B_U4.6, B_U4_RC.1
BOT_U4_CZ_N: B_U4_CZ.1, B_U4_RC.2
BOT_U4_FB: B_U4.5, B_U4_RH.2, B_U4_RL.1
BOT_U4_RT: B_U4.4, B_U4_RT_R.1
BOT_U4_SW: B_U4.8, B_U4_CB.2, B_U4_D.2, B_U4_L.1
BOT_USB_VBUS: B_D5.1, B_J2.18
BOT_V_TRIP_HI: B_R7.2, B_R8.1, B_UM1_CMP.3, B_UM2_CMP.3
BOT_V_TRIP_LO: B_R8.2, B_R9.1, B_UM1_CMP.6, B_UM2_CMP.6
MID_3V3_SYS: M_C1.1, M_C2.1, M_C3.1, M_C5.1, M_C6.1, M_J2.9, M_J2.10, M_J3.3, M_J3.4, M_R1.1, M_R2.1, M_R3.1, M_R6.1, M_R7.1, M_R9.1, M_R10.1, M_R13.1, M_R14.1, M_R15.1, M_U1.2, M_U2.8, M_U3.24
MID_5V_SYS: M_BZ1.1, M_D1.2, M_J2.3, M_J2.4, M_J2.5, M_J2.6
MID_AGND: M_J2.27, M_J2.29
MID_AUDIO_B: M_Q2.1, M_R8.2
MID_AUDIO_LOW: M_BZ1.2, M_D1.1, M_Q2.2
MID_AUDIO_PWM: M_J3.23, M_R8.1, M_U1.8
MID_BTN1: M_J3.1, M_U1.4
MID_BTN2: M_J2.2, M_U1.5
MID_BTN3: M_J2.40, M_U1.6
MID_BTN4: M_J3.39, M_U1.7
MID_DISP_BL: M_J3.38, M_U1.37
MID_DISP_CS: M_J3.36, M_U1.18
MID_DISP_RST: M_J3.37, M_U1.9
MID_ESP_BOOT: M_R2.2, M_SW2.1, M_U1.27
MID_ESP_EN: M_C4.1, M_R1.2, M_SW1.1, M_U1.3
MID_EXP_P6: M_C7.1, M_R9.2, M_R11.2, M_U3.10
MID_EXP_P7: M_C8.1, M_R10.2, M_R12.2, M_U3.11
MID_EXP_P8: M_C9.1, M_R14.2, M_R16.2, M_U3.13
MID_EXP_P9: M_C10.1, M_R15.2, M_R17.2, M_U3.14
MID_HOOD_A: M_D4.1, M_J2.38, M_U4.4
MID_HOOD_B: M_D4.2, M_J2.39, M_U4.3
MID_HW_TRIP1: M_J2.30, M_U3.4
MID_HW_TRIP2: M_J2.31, M_U3.5
MID_I2C_SCL: M_J3.5, M_R7.2, M_U1.17, M_U3.22
MID_I2C_SDA: M_J3.7, M_R6.2, M_U1.12, M_U3.23
MID_I_SENSE1: M_J2.26, M_U1.39
MID_I_SENSE2: M_J2.28, M_U1.38
MID_M1_INA: M_J2.16, M_U1.31
MID_M1_INB: M_J2.17, M_U1.32
MID_M2_INA: M_J2.20, M_U1.33
MID_M2_INB: M_J2.22, M_U1.24
MID_PGND: M_C1.2, M_C2.2, M_C3.2, M_C4.2, M_C5.2, M_C6.2, M_C7.2, M_C8.2, M_C9.2, M_C10.2, M_D2.2, M_D3.2, M_D5.2, M_D6.2, M_J2.1, M_J2.7, M_J2.8, M_J2.11, M_J2.12, M_J2.14, M_J2.15, M_J2.19, M_J2.21, M_J3.6, M_J3.8, M_J3.9, M_J3.11, M_J3.13, M_J3.17, M_J3.19, M_J3.22, M_J3.25, M_J3.26, M_J3.27, M_J3.28, M_J3.29, M_J3.30, M_J3.33, M_J3.40, M_J7.A1, M_J7.A12, M_J7.B1, M_J7.B12, M_J7.SH, M_Q2.3, M_R4.2, M_R18.2, M_R19.2, M_SW1.2, M_SW2.2, M_U1.1, M_U1.40, M_U1.41, M_U2.5, M_U3.2, M_U3.3, M_U3.12, M_U3.21, M_U5.2
MID_PRESENCE_INT: M_J3.21, M_U3.8
MID_QSPI_CLK: M_J3.24, M_U1.20
MID_QSPI_D0: M_J3.31, M_U1.19
MID_QSPI_D1: M_J3.32, M_U1.21
MID_QSPI_D2: M_J3.34, M_U1.22
MID_QSPI_D3: M_J3.35, M_U1.23
MID_REED1_IN: M_D2.1, M_J2.36, M_R11.1
MID_REED2_IN: M_D3.1, M_J2.24, M_R12.1
MID_RELAY_CTL: M_J2.33, M_U3.9, M_U4.2
MID_RELAY_LED: M_R13.2, M_U4.1
MID_RS485_A: M_J2.34, M_R3.2, M_R5.1, M_U2.6
MID_RS485_B: M_J2.35, M_R4.1, M_R5.2, M_U2.7
MID_RS485_DIR: M_J3.15, M_J3.16, M_U1.25, M_U2.2, M_U2.3
MID_SAB1_IN: M_D5.1, M_J2.37, M_R16.1
MID_SAB2_IN: M_D6.1, M_J2.25, M_R17.1
MID_STAR_EN: M_J2.23, M_U3.7
MID_TRIP_RST: M_J2.32, M_U3.6
MID_UART485_RX: M_J3.14, M_U1.11, M_U2.1
MID_UART485_TX: M_J3.12, M_U1.10, M_U2.4
MID_UART_AUX_RX: M_J3.20, M_U1.34
MID_UART_AUX_TX: M_J3.18, M_U1.35
MID_USB_CC1: M_J7.A5, M_R18.1
MID_USB_CC2: M_J7.B5, M_R19.1
MID_USB_DN: M_U1.13, M_U5.6
MID_USB_DN_C: M_J7.A7, M_J7.B7, M_U5.1
MID_USB_DP: M_U1.14, M_U5.4
MID_USB_DP_C: M_J7.A6, M_J7.B6, M_U5.3
MID_USB_VBUS: M_J2.18, M_J7.A4, M_J7.A9, M_J7.B4, M_J7.B9, M_U5.5
TOP_3V3_SYS: T_C1.1, T_C3.1, T_C4.1, T_J2.9, T_J2.10, T_J3.3, T_J3.4, T_J5.8, T_J5.9, T_R5.1, T_U2.3, T_U3.1, T_U3.11
TOP_5V_SYS: T_J2.3, T_J2.4, T_J2.5, T_J2.6, T_R_BL.1
TOP_6V2_STAR_F: T_J2.13, T_Q2.2, T_R4.1
TOP_AGND: T_J2.27, T_J2.29
TOP_BTN1: T_J3.1, T_SW1.1
TOP_BTN2: T_J2.2, T_SW2.1
TOP_BTN3: T_J2.40, T_SW3.1
TOP_BTN4: T_J3.39, T_SW4.1
TOP_DISP_BL: T_J3.38, T_Q_BL.1, T_R_BLG.1
TOP_DISP_CS: T_J3.36, T_J5.7
TOP_DISP_LEDA: T_J5.10, T_R_BL.2
TOP_DISP_LEDK: T_J5.11, T_Q_BL.2
TOP_DISP_RST: T_J3.37, T_J5.4
TOP_EN_LOOP: T_J3.2, T_SW5.1
TOP_I2C_SCL: T_J3.5, T_U2.2, T_U3.10
TOP_I2C_SDA: T_J3.7, T_U2.1, T_U3.9
TOP_PGND: T_C1.2, T_C2.2, T_C3.2, T_C4.2, T_J2.1, T_J2.7, T_J2.8, T_J2.11, T_J2.12, T_J2.14, T_J2.15, T_J2.19, T_J2.21, T_J3.6, T_J3.8, T_J3.9, T_J3.11, T_J3.13, T_J3.17, T_J3.19, T_J3.22, T_J3.25, T_J3.26, T_J3.27, T_J3.28, T_J3.29, T_J3.30, T_J3.33, T_J3.40, T_J5.2, T_J5.12, T_J6.2, T_Q1.3, T_Q_BL.3, T_R_BLG.2, T_SW1.2, T_SW2.2, T_SW3.2, T_SW4.2, T_SW5.2, T_U2.4, T_U3.2, T_U3.3, T_U3.4, T_U3.6, T_U3.12
TOP_PRESENCE_INT: T_J3.21, T_U3.7
TOP_QSPI_CLK: T_J3.24, T_J5.6
TOP_QSPI_D0: T_J3.31, T_J5.5
TOP_QSPI_D1: T_J3.32, T_J5.3
TOP_RS485_DIR: T_J3.15, T_J3.16
TOP_STAR_B: T_Q1.1, T_R3.2
TOP_STAR_EN: T_J2.23, T_R3.1
TOP_STAR_G: T_Q1.2, T_Q2.1, T_R4.2
TOP_STAR_OUT: T_F1.2, T_J6.1, T_Q2.3
TOP_STAR_SW: T_C2.1, T_F1.1
TOP_TOF_XSHUT: T_R5.2, T_U3.5

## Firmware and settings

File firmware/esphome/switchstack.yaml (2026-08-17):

# =============================================================================
# KiCad SwitchStack - ESPHome-Konfiguration
# =============================================================================
# Zielhardware : ESP32-S3-WROOM-1-N16R8
# Display      : 1,69" LCD rechteckig, ST7789, 240x280, quer eingebaut
# Front        : Busch-Jaeger Zentralscheibe 6435-914 (balance SI) im Rahmen
#                1721-914. Ihr Fenster misst 32,70 x 27,00 mm - die aktive
#                Flaeche des Panels ist 32,63 x 27,97 und fuellt es aus.
# Bedienung    : VIER Ecktaster unter den Druckkreuzen der Scheibe. Die
#                Symbole stehen auf den Achsen, die Kraft kommt an den Ecken
#                an - jede Richtung ist ein PAAR. Aufloesung siehe unten.
#
# Geprueft mit `esphome compile` (2026.7.4 / IDF 5.5.5): uebersetzt, RAM 35 %,
# Flash 56 %. Ungeprueft bleibt die Laufzeit - besonders die Offsets des
# 240x280-Panels (0/20) und ob die Zentralscheibe die Taster sauber trifft.
#
# Die Praesenz-Dunkeltastung unten (VL53L1X, kein Radar mehr) ist beim LCD
# reiner Komfort und Stromsparen, keine Schutzmassnahme (kein Einbrennen).
#
# STAND: Die Jalousien laufen hier als template-Cover auf ZEIT. Die
# stromabhaengige Lasterkennung braucht PWM-synchrones ADC-Sampling und ist in
# reinem YAML nicht umsetzbar - siehe docs/09-display-and-mcu.md, Abschnitt 4.
# Sie zieht in eine eigene C++-External-Component um.
#
# Der Hardware-Hard-Trip (Comparator + Latch) wirkt unabhaengig von dieser
# Konfiguration und bleibt der eigentliche Schutz.
# =============================================================================

substitutions:
  name: switchstack
  friendly_name: SwitchStack

  # --- Fahrzeiten (Sekunden) --------------------------------------------------
  # Fahrzeit real 18 s (Datenblatt) + Reserve, siehe docs/11-motor-data.md
  travel_time: "30s"
  # Mechanische Stopzeit vor Umpolung
  reversal_pause: "300ms"

esphome:
  name: ${name}
  friendly_name: ${friendly_name}
  # Beim Start alles stromlos: beide Brueckenzweige low = Motor aus.
  on_boot:
    priority: 600
    then:
      - output.set_level: {id: m1_ina, level: 0%}
      - output.set_level: {id: m1_inb, level: 0%}
      - output.set_level: {id: m2_ina, level: 0%}
      - output.set_level: {id: m2_inb, level: 0%}

esp32:
  board: esp32-s3-devkitc-1
  variant: esp32s3
  framework:
    type: esp-idf

psram:
  mode: octal
  speed: 80MHz

logger:
  # ESP32-S3 hat nativen USB - kein separater USB-UART-Baustein noetig.
  hardware_uart: USB_SERIAL_JTAG

api:
  encryption:
    key: !secret api_encryption_key

ota:
  - platform: esphome
    password: !secret ota_password

# WLAN ist ausdruecklich sekundaer. In einer massiven Unterputzdose hinter einer
# Frontplatte ist der Empfang schwach - RS-485 ist der primaere Weg.
wifi:
  ssid: !secret wifi_ssid
  password: !secret wifi_password
  ap:
    ssid: ${friendly_name} Fallback

captive_portal:

# -----------------------------------------------------------------------------
# Busse
# -----------------------------------------------------------------------------

i2c:
  sda: GPIO8
  scl: GPIO9
  scan: true
  id: bus_i2c

# Der ST7789 ist 4-Draht-SPI, kein QSPI. Die Netznamen am Stack heissen
# weiterhin QSPI_*, weil sie durch alle drei Boards laufen und eine
# Umbenennung den Bottom-Schaltplan aendern wuerde (dessen Layout ist geroutet).
# Belegung: QSPI_CLK = SCK, QSPI_D0 = MOSI, QSPI_D1 = DC.
spi:
  id: bus_disp
  clk_pin: GPIO12
  mosi_pin: GPIO11

# RS-485: primaere Kommunikation. DE/RE ueber flow_control_pin.
uart:
  - id: uart_rs485
    tx_pin: GPIO17
    rx_pin: GPIO18
    baud_rate: 19200
  # Reserve-UART auf J7 des Top-Boards (unbestueckt). Hiess bis Stack-Pinout
  # v0.4 uart_radar - der Radar ist durch den VL53L1X ersetzt.
  - id: uart_aux
    tx_pin: GPIO42
    rx_pin: GPIO41
    baud_rate: 115200

# GPIO-Expander fuer die langsamen Signale - entlastet das knappe Pinbudget.
# PCF8575 (16 Bit) statt PCF8574: Mit vier Reed-Kontakten - Verschluss UND
# Sabotage je Fenster - reichen acht Portpins nicht mehr. Gleiche Adresse,
# gleicher Treiber, ein Bauteil statt zwei.
pcf8574:
  - id: expander
    address: 0x20
    pcf8575: true

# -----------------------------------------------------------------------------
# Ausgaenge
# -----------------------------------------------------------------------------

output:
  - platform: ledc
    id: disp_backlight
    pin: GPIO43
    frequency: 2000Hz

  # Je Brueckenzweig ein PWM-faehiger Ausgang (INA/INB) - die Richtung
  # entsteht daraus, welcher Zweig moduliert. Pins == Mid-Schaltplan.
  - platform: ledc
    id: m1_ina
    pin: GPIO38
    frequency: 20000Hz     # oberhalb des Hoerbereichs
  - platform: ledc
    id: m1_inb
    pin: GPIO39
    frequency: 20000Hz
  - platform: ledc
    id: m2_ina
    pin: GPIO40
    frequency: 20000Hz
  - platform: ledc
    id: m2_inb
    pin: GPIO47
    frequency: 20000Hz

  - platform: ledc
    id: buzzer_out
    pin: GPIO15
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

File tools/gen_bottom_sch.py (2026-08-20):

#!/usr/bin/env python3
"""
Erzeugt den Schaltplan des Bottom-Boards (24 V, DC/DC, 2 x H-Bruecke).

    python3 tools/gen_bottom_sch.py

Die Konnektivitaet steht hier als Quelltext und wird nach dem Erzeugen mit
kicad-cli als Netzliste zurueckgelesen und gegen genau diese Vorgabe geprueft.

WICHTIG - was dieser Schaltplan ist und was nicht:
  * Er ist netzlistenkorrekt und in KiCad oeffenbar.
  * Er ist NICHT geprueft im Sinne einer Schaltungsreview. Bauteilwerte sind
    berechnet, aber Referenzdesigns der Hersteller sind noch nicht abgeglichen.
  * Vor Fertigung: Pinbelegung jedes ICs gegen das Datenblatt pruefen, die
    Regler nach Hersteller-Referenzlayout aufbauen.

Auslegung nach docs/11-motor-data.md Abschnitt 5. Der Blockierstrom ist seit
dem 17.08.2026 gemessen: 1,7 A je Motor (24 V an 14 Ohm Ankerwiderstand), nicht
die zuvor angenommenen 25 A. Shunt und Trip-Teiler sind entsprechend neu
gerechnet - siehe die Kommentare bei R_*_SH und R7/R8/R9.
"""

import os
import re
import subprocess
import sys

sys.path.insert(0, os.path.dirname(os.path.abspath(__file__)))
from kisch import Schematic                                    # noqa: E402
from stack_pinout import connect_stack                         # noqa: E402

ROOT = os.path.dirname(os.path.dirname(os.path.abspath(__file__)))
OUT = os.path.join(ROOT, "hardware", "bottom_power_motor", "bottom_power_motor.kicad_sch")

R0603 = "Resistor_SMD:R_0603_1608Metric"
C0603 = "Capacitor_SMD:C_0603_1608Metric"
C1210 = "Capacitor_SMD:C_1210_3225Metric"
SOT23 = "Package_TO_SOT_SMD:SOT-23"
SOIC8 = "Package_SO:SOIC-8_3.9x4.9mm_P1.27mm"


def build():
    s = Schematic("bottom_power_motor",
                  "SwitchStack BOTTOM - Power & Motor", paper="A2")

    # =====================================================================
    # 1. Leistungseingang und Schutz
    # =====================================================================
    # EIN Steckverbinder fuer die gesamte Feldverdrahtung, 18.08.2026.
    #
    # Bisher verteilten sich die Anschluesse auf vier Stecker an zwei
    # Platinen: Leistung und Motoren hier, RS485, vier Reed-Kontakte und der
    # Haubenkontakt auf dem Mid-Board mitten im Stapel. Die Feldkabel zerrten
    # damit an drei Leiterplatten, und der Stapel liess sich nicht als Ganzes
    # ein- und ausbauen.
    #
    # Moeglich wurde die Zusammenfassung erst dadurch, dass die diskrete
    # H-Bruecke der integrierten gewichen ist - die acht MOSFETs belegten
    # genau die Flaeche, die dieser Stecker braucht (docs/14).
    #
    #   1  24V_IN       9  RS485_B
    #   2  PGND        10  REED1_IN
    #   3  M1_A        11  SAB1_IN
    #   4  M1_B        12  REED2_IN
    #   5  M2_A        13  SAB2_IN
    #   6  M2_B        14  HOOD_A
    #   7  PGND        15  HOOD_B
    #   8  RS485_A     16  PGND
    #
    # Kontakt 7 trennt die PWM-fuehrenden Motorleitungen von RS485 und den
    # Reed-Eingaengen. Micro-Fit 3.0 traegt 5 A je Kontakt, der Summenstrom
    # betraegt im unguenstigsten Fall 4,1 A - das traegt der eine 24-V-Kontakt.
    #
    # ALLES SELV. Der Haubenkontakt ist ueber den PhotoMOS auf dem Mid-Board
    # potentialfrei, darf aber nur Kleinspannung schalten - im selben Gehaeuse
    # wie die 24-V-Zufuehrung ist alles andere unzulaessig.
    s.add("J1", "Connector_Generic:Conn_02x08_Odd_Even", "Feld 16p",
          "Connector_Molex:Molex_Micro-Fit_3.0_43045-1612_2x08_P3.00mm_Vertical",
          MPN="Molex 43045-1612, 2x8, stehend - EIN Stecker fuer alles, SELV")
    s.connect("24V_IN",   ("J1", "1"))
    s.connect("PGND",     ("J1", "2"), ("J1", "7"), ("J1", "16"))
    s.connect("M1_A",     ("J1", "3"))
    s.connect("M1_B",     ("J1", "4"))
    s.connect("M2_A",     ("J1", "5"))
    s.connect("M2_B",     ("J1", "6"))
    s.connect("RS485_A",  ("J1", "8"))
    s.connect("RS485_B",  ("J1", "9"))
    s.connect("REED1_IN", ("J1", "10"))
    s.connect("SAB1_IN",  ("J1", "11"))
    s.connect("REED2_IN", ("J1", "12"))
    s.connect("SAB2_IN",  ("J1", "13"))
    s.connect("HOOD_A",   ("J1", "14"))
    s.connect("HOOD_B",   ("J1", "15"))

    # Sicherung - Wert messabhaengig
    # FLINK, nicht traege: Die NANO2-453 (Slo-Blo) endet laut Littelfuse
    # bei 5 A; 15 A gibt es nur flink (451, z. B. 0451015.MRL). Sachlich
    # gleichwertig - die Sicherung schuetzt die Leitung, den Motor
    # schuetzt der HW-Trip Groessenordnungen frueher.
    s.add("F1", "Device:Fuse", "15A flink",
          "Fuse:Fuse_Littelfuse-NANO2-451_453",
          MPN="SMD NANO2, messabhaengig - siehe docs/11")
    s.connect("24V_IN", ("F1", "1"))
    s.connect("24V_F",  ("F1", "2"))

    # TVS gegen Transienten
    s.add("D1", "Device:D_TVS", "SMBJ30A", "Diode_SMD:D_SMB")
    s.connect("24V_F", ("D1", "1"))
    s.connect("PGND",  ("D1", "2"))

    # Verpolschutz: P-MOSFET high-side, Gate ueber R gegen GND, Zener begrenzt Ugs
    s.add("Q1", "SwitchStack:Q_PMOS_GSD", "P-FET 40V 30A",
          "Package_SO:PowerPAK_SO-8_Single",
          MPN="Vishay SIR4409DP-T1-GE3 (P-Kanal -40V/60A; Mouser, Handbestueckung) - Pad-Zuordnung siehe PAD_MAP in gen_layouts")
    s.connect("24V_GATE_P", ("Q1", "1"))
    s.connect("24V_F",      ("Q1", "2"))
    s.connect("24V_PROT",   ("Q1", "3"))
    # SEIT DEM 19.08.2026 IST DER GATE-PULLDOWN EINE SCHLEIFE DURCH DEN
    # STAPEL, nicht mehr ein fester Draht nach PGND. R1 endet auf EN_LOOP;
    # das Netz laeuft ueber Stapelkontakt B2 zum Top-Board, dort durch den
    # Hauptschalter SW5 und zurueck nach PGND. Folge:
    #
    #   Top-Board fehlt      -> Schleife offen -> Q1 sperrt -> alles aus
    #   SW5 aus              -> dito
    #   SW5 ein              -> Gate ueber R1/R1B geteilt, Q1 leitet
    #
    # R1B haelt das Gate bei offener Schleife DEFINIERT an der Source -
    # vorher hing es nur am Zener-Leckstrom. Teiler bei geschlossener
    # Schleife: 24 V * 100k/1,1M = 2,2 V am Gate, Ugs = -21,8 V, von D2 auf
    # -12 V begrenzt. Schleifenstrom rund 20 uA.
    s.add("R1", "Device:R", "100k", R0603)
    s.connect("24V_GATE_P", ("R1", "1"))
    s.connect("EN_LOOP",    ("R1", "2"))
    s.add("R1B", "Device:R", "1M", R0603)
    s.connect("24V_F",      ("R1B", "1"))
    s.connect("24V_GATE_P", ("R1B", "2"))
    s.add("D2", "Device:D_Zener", "12V", "Diode_SMD:D_SOD-123")
    s.connect("24V_F",      ("D2", "1"))
    s.connect("24V_GATE_P", ("D2", "2"))

    # Eingangs- und Bulkkondensatoren
    # Bulk niedrigbauend: Hoehenbudget Bottom-Oberseite ist ~10 mm
    # (docs/04). Polymer-Typen, Wert nach Messung M2 ggf. anheben.
    for ref, val, fp in (("C1", "100n", C0603), ("C2", "10u", C1210),
                         ("C3", "220u/35V Polymer", "Capacitor_SMD:CP_Elec_8x6.5"),
                         ("C4", "220u/35V Polymer", "Capacitor_SMD:CP_Elec_8x6.5")):
        s.add(ref, "Device:C", val, fp)
        s.connect("24V_PROT", (ref, "1"))
        s.connect("PGND",     (ref, "2"))

    # =====================================================================
    # 2. Die 12-V-Gatespannung ist am 18.08.2026 entfallen
    # =====================================================================
    # Sie versorgte ausschliesslich die Bootstrap-Treiber IR2104 der diskreten
    # H-Bruecke. Mit dem Wechsel auf die integrierte Bruecke DRV8871 braucht
    # niemand mehr eine eigene Gatespannung - der Treiber erzeugt sie intern.
    #
    # Entfallen sind damit der Vorwiderstand, die Z-Diode, der Regler L78L12
    # im SOT-89 und seine beiden Kondensatoren: fuenf Bauteile und eine ganze
    # Spannungsschiene weniger.

    # =====================================================================
    # 3. DC/DC-Wandler
    # =====================================================================
    def buck_tps54360(u, rail, r_hi, r_lo, l_val, cout, cout_fp):
        """TPS54360: 60 V Eingang, Vref 0,8 V."""
        s.add(u, "Regulator_Switching:TPS54360DDA", "TPS54360",
              "Package_SO:HSOP-8-1EP_3.9x4.9mm_P1.27mm_EP2.41x3.1mm", MPN="TPS54360DDAR, LCSC C44377")
        s.connect("24V_PROT", (u, "2"))
        s.connect("PGND",     (u, "7"), (u, "9"))
        s.connect(u + "_SW",   (u, "8"))
        s.connect(u + "_BOOT", (u, "1"))
        s.connect(u + "_FB",   (u, "5"))
        s.connect(u + "_COMP", (u, "6"))
        s.connect(u + "_RT",   (u, "4"))
        s.connect("24V_EN",    (u, "3"))
        # Bootstrap
        s.add(u + "_CB", "Device:C", "100n", C0603)
        s.connect(u + "_BOOT", (u + "_CB", "1"))
        s.connect(u + "_SW",   (u + "_CB", "2"))
        # Speicherdrossel und Freilaufdiode
        s.add(u + "_L", "Device:L", l_val, "Inductor_SMD:L_Bourns_SRP7028A_7.3x6.6mm")
        s.connect(u + "_SW", (u + "_L", "1"))
        s.connect(rail,      (u + "_L", "2"))
        s.add(u + "_D", "Device:D_Schottky", "60V 3A", "Diode_SMD:D_SMB")
        s.connect("PGND",    (u + "_D", "1"))
        s.connect(u + "_SW", (u + "_D", "2"))
        # Rueckkopplung
        s.add(u + "_RH", "Device:R", r_hi, R0603)
        s.connect(rail,      (u + "_RH", "1"))
        s.connect(u + "_FB", (u + "_RH", "2"))
        s.add(u + "_RL", "Device:R", r_lo, R0603)
        s.connect(u + "_FB", (u + "_RL", "1"))
        s.connect("PGND",    (u + "_RL", "2"))
        # Frequenz und Kompensation
        s.add(u + "_RT_R", "Device:R", "100k", R0603,
              MPN="fsw ca. 500 kHz - gegen Datenblatt pruefen")
        s.connect(u + "_RT", (u + "_RT_R", "1"))
        s.connect("PGND",    (u + "_RT_R", "2"))
        s.add(u + "_RC", "Device:R", "10k", R0603)
        s.connect(u + "_COMP", (u + "_RC", "1"))
        s.connect(u + "_CZ_N", (u + "_RC", "2"))
        s.add(u + "_CZ", "Device:C", "3n3", C0603)
        s.connect(u + "_CZ_N", (u + "_CZ", "1"))
        s.connect("PGND",      (u + "_CZ", "2"))
        # Ausgangskondensator
        s.add(u + "_CO", "Device:C", cout, cout_fp)
        s.connect(rail,   (u + "_CO", "1"))
        s.connect("PGND", (u + "_CO", "2"))

    # UVLO-Teiler, gemeinsam fuer beide 24-V-Wandler (Start ab ca. 18 V)
    s.add("R3", "Device:R", "392k", R0603)
    s.connect("24V_PROT", ("R3", "1"))
    s.connect("24V_EN",   ("R3", "2"))
    s.add("R4", "Device:R", "88k7", R0603)
    s.connect("24V_EN", ("R4", "1"))
    s.connect("PGND",   ("R4", "2"))

    # 24 V -> 5 V : 0,8 x (1 + 53k6/10k2) = 5,00 V
    buck_tps54360("U2", "5V_BUCK", "53k6", "10k2", "10u", "47u", C1210)
    # 24 V -> 6,2 V : 0,8 x (1 + 68k1/10k0) = 6,25 V
    buck_tps54360("U4", "6V2_STAR", "68k1", "10k0", "33u", "22u", C1210)

    # 5 V -> 3,3 V : TLV62569, Vref 0,6 V -> 0,6 x (1 + 180k/40k2) = 3,29 V
    s.add("U3", "Regulator_Switching:TLV62569DBV", "TLV62569",
          "Package_TO_SOT_SMD:SOT-23-5", MPN="TLV62569DBVR, LCSC C141836")
    s.connect("5V_SYS", ("U3", "4"), ("U3", "1"))
    s.connect("PGND",   ("U3", "2"))
    s.connect("U3_SW",  ("U3", "3"))
    s.connect("U3_FB",  ("U3", "5"))
    s.add("L1", "Device:L", "2u2", "Inductor_SMD:L_Bourns_SRP5030T")
    s.connect("U3_SW",   ("L1", "1"))
    s.connect("3V3_SYS", ("L1", "2"))
    s.add("R5", "Device:R", "180k", R0603)
    s.connect("3V3_SYS", ("R5", "1"))
    s.connect("U3_FB",   ("R5", "2"))
    s.add("R6", "Device:R", "40k2", R0603)
    s.connect("U3_FB", ("R6", "1"))
    s.connect("PGND",  ("R6", "2"))
    s.add("C7", "Device:C", "22u", C1210)
    s.connect("3V3_SYS", ("C7", "1"))
    s.connect("PGND",    ("C7", "2"))

    # USB-ORing: 5V_BUCK und USB_VBUS speisen 5V_SYS, keine Rueckspeisung
    for ref, src in (("D4", "5V_BUCK"), ("D5", "USB_VBUS")):
        s.add(ref, "Device:D_Schottky", "40V 3A", "Diode_SMD:D_SMA",
              MPN="Vf klein waehlen - Verlust siehe docs/01")
        s.connect(src,      (ref, "1"))
        s.connect("5V_SYS", (ref, "2"))
    s.add("C8", "Device:C", "22u", C1210)
    s.connect("5V_SYS", ("C8", "1"))
    s.connect("PGND",   ("C8", "2"))

    # Stern-Ausgang mit eigener Absicherung
    s.add("F2", "Device:Polyfuse", "0.5A", "Fuse:Fuse_1812_4532Metric")
    s.connect("6V2_STAR",   ("F2", "1"))
    s.connect("6V2_STAR_F", ("F2", "2"))
    s.add("C9", "Device:C", "22u", C1210)
    s.connect("6V2_STAR_F", ("C9", "1"))
    s.connect("PGND",       ("C9", "2"))
    # Sternstecker sitzt auf dem TOP-Board (Frontanschluss); hier bleibt nur
    # die abgesicherte Schiene 6V2_STAR_F, die ueber J_STK_A nach oben geht.

    # =====================================================================
    # 4. Motorkanaele
    # =====================================================================
    def motor_channel(n, out_a, out_b):
        """Integrierte Vollbruecke DRV8871, Inline-Strommessung,
        Comparator-Fenster und Latch fuer den Hardware-Trip.

        BIS ZUM 18.08.2026 STAND HIER EINE DISKRETE BRUECKE aus zwei IR2104
        und vier N-FETs je Kanal - acht FETs und vier Treiber insgesamt. Sie
        war so gewaehlt worden, weil der Blockierstrom unbekannt war und ein
        integrierter Treiber ihn moeglicherweise nicht ausgehalten haette.

        Inzwischen ist der Blockierstrom vierfach belegt: drei eigene
        Messungen und die Bauteilwahl des Original-Controllers, der genau
        diesen Weg geht - zwei integrierte Bruecken (Infineon BTM7700G), je
        eine pro Motor (docs/14). Bei 1,7 A ist die diskrete Bruecke aus
        60-A-FETs schlicht ueberdimensioniert.

        Der DRV8871 statt des BTM7700G des Originals, aus einem Grund:
        Spannungsreserve. Der BTM7700G ist bis 28 V kurzschlussfest, unsere
        Schiene liegt bei 24 V +10 % = 26,4 V - das ist zu knapp. Der DRV8871
        vertraegt 45 V und 3,6 A Spitze.

        WAS DADURCH ENTFAELLT, je Kanal:
          4 N-FET PowerPAK SO-8, 2 IR2104, 4 Gate-Widerstaende,
          2 Bootstrap-Dioden, 2 Bootstrap-Kondensatoren
        und einmal fuer das ganze Board die 12-V-Gatespannung samt Regler.

        WAS BLEIBT: Shunt, INA240A2, Fensterkomparator und Latch. Der DRV8871
        bringt zwar eigene Strombegrenzung, Uebertemperatur- und
        Unterspannungsabschaltung mit, aber keine davon meldet sich nach
        aussen und keine schuetzt die Mechanik. Die eigene Messkette bleibt
        also - sie liefert den Messwert fuer die Endlagenerkennung, und der
        Latch bleibt die firmwareunabhaengige Notbremse.

        WIE DER LATCH JETZT ABSCHALTET: Der DRV8871 hat keinen Enable-Pin.
        Statt auf ~SD zu wirken, sperrt der Latch die beiden Eingaenge ueber
        ein UND-Gatter je Leitung; mit IN1 = IN2 = 0 geht die Bruecke in den
        hochohmigen Zustand.
        """
        p = "M%d" % n
        sd = p + "_SD"                       # aktiv low: Endstufe aus

        s.add("U%s_BR" % p, "Driver_Motor:DRV8871DDA", "DRV8871",
              "Package_SO:HSOP-8-1EP_3.9x4.9mm_P1.27mm_EP2.41x3.1mm_ThermalVias",
              MPN="45 V, 3,6 A Spitze, Strombegrenzung ueber ILIM - , LCSC C75864"
                  "Thermalpad an PGND anbinden")
        s.connect("PGND",      ("U%s_BR" % p, "1"), ("U%s_BR" % p, "7"),
                  ("U%s_BR" % p, "9"))
        s.connect(p + "_GB",   ("U%s_BR" % p, "2"))    # IN2, ueber UND-Gatter
        s.connect(p + "_GA",   ("U%s_BR" % p, "3"))    # IN1, ueber UND-Gatter
        s.connect(p + "_ILIM", ("U%s_BR" % p, "4"))
        s.connect("24V_PROT",  ("U%s_BR" % p, "5"))
        s.connect(p + "_SWA",  ("U%s_BR" % p, "6"))    # OUT1 -> Shunt
        s.connect(out_b,       ("U%s_BR" % p, "8"))    # OUT2 direkt

        # Strombegrenzung des Treibers. Sie ist die INNERE Grenze und liegt
        # bewusst UEBER dem Blockierstrom von 1,7 A, damit der Anschlag - ein
        # normaler Betriebszustand - sie nicht dauernd anspricht. 2,7 A nach
        # der Datenblattformel I = V_ILIM / (K * R); Wert vor der Bestellung
        # gegen das Datenblatt nachrechnen.
        s.add("R_%s_IL" % p, "Device:R", "33k0", R0603,
              MPN="Strombegrenzung DRV8871 - Wert gegen Datenblatt pruefen")
        s.connect(p + "_ILIM", ("R_%s_IL" % p, "1"))
        s.connect("PGND",      ("R_%s_IL" % p, "2"))

        # Bulk direkt an der Bruecke
        # POLYMER statt 1210-Keramik (20.08.2026): "100u 50V" als
        # 1210-MLCC EXISTIERT NICHT - Keramik in 1210 endet bei 100 uF /
        # ~10 V. Aufgefallen beim LCSC-Abgleich. Gleiche Bauform wie C3/C4.
        s.add("C_%s_BR" % p, "Device:C", "100u/35V Polymer",
              "Capacitor_SMD:CP_Elec_8x6.5",
              MPN="Bulk je Bruecke. Das Original kommt mit 47 uF fuer BEIDE "
                  "Motoren aus (docs/14) - 100 uF je Kanal ist reichlich")
        s.connect("24V_PROT", ("C_%s_BR" % p, "1"))
        s.connect("PGND",     ("C_%s_BR" % p, "2"))

        # UND-Gatter: Der Latch sperrt beide Eingaenge gleichzeitig.
        for leg, inp in (("A", "%s_INA" % p), ("B", "%s_INB" % p)):
            g = "U%s_G%s" % (p, leg)
            s.add(g, "74xGxx:74AHC1G08", "74AHC1G08",
                  "Package_TO_SOT_SMD:SOT-353_SC-70-5", MPN="74AHC1G08GW, LCSC C12490")
            s.connect(inp,            (g, "1"))
            s.connect(sd,             (g, "2"))
            s.connect("PGND",         (g, "3"))
            s.connect("%s_G%s" % (p, leg), (g, "4"))
            s.connect("3V3_SYS",      (g, "5"))

        # Inline-Shunt im Zweig A - misst in JEDEM PWM-Zustand.
        # 5 mOhm, nicht 1 mOhm: Der gemessene Blockierstrom von 1,7 A haette
        # am 1-mOhm-Shunt nur 1,6 mV erzeugt, verstaerkt 80 mV - zu wenig, um
        # Lauf (0,3-1,0 A) von Anschlag (1,7 A) zu trennen. Mit 5 mOhm und
        # INA240A2 (Verstaerkung 50) sind es 0,25 V/A, Messbereich +/-6,6 A,
        # Verlustleistung bei 2 A nur 20 mW.
        s.add("R_%s_SH" % p, "Device:R_Shunt", "5m0 1W",
              "Resistor_SMD:R_2512_6332Metric",
              MPN="4-Terminal, Kelvin - Pflicht")
        s.connect(p + "_SWA", ("R_%s_SH" % p, "1"), ("R_%s_SH" % p, "3"))
        s.connect(out_a,      ("R_%s_SH" % p, "2"), ("R_%s_SH" % p, "4"))
        # Zweig B ohne Shunt direkt an den Steckverbinder
        s.add("R_%s_LNK" % p, "Device:R", "0R", R0603,
              MPN="Bruecke, erlaubt spaeteres Auftrennen zur Messung")
        s.connect(p + "_SWB", ("R_%s_LNK" % p, "1"))
        s.connect(out_b,      ("R_%s_LNK" % p, "2"))

        # Strommessverstaerker, bidirektional, aus 3,3 V -> ADC-sicher
        amp = "U%s_CS" % p
        s.add(amp, "Amplifier_Current:INA240A2D", "INA240A2", SOIC8,
              MPN="Pinbelegung gegen Datenblatt pruefen, LCSC C2060768")
        s.connect(p + "_SWA",  (amp, "8"))
        s.connect(out_a,       (amp, "1"))
        s.connect("AGND",      (amp, "2"), (amp, "4"))
        s.connect("3V3_SYS",   (amp, "6"), (amp, "7"))
        s.connect("AGND",      (amp, "3"))
        s.connect(p + "_ISNS", (amp, "5"))
        s.add("C_%s_CS" % p, "Device:C", "100n", C0603)
        s.connect("3V3_SYS", ("C_%s_CS" % p, "1"))
        s.connect("AGND",    ("C_%s_CS" % p, "2"))
        # RC-Filter zum ADC
        s.add("R_%s_F" % p, "Device:R", "1k", R0603)
        s.connect(p + "_ISNS", ("R_%s_F" % p, "1"))
        s.connect("I_SENSE%d" % n, ("R_%s_F" % p, "2"))
        s.add("C_%s_F" % p, "Device:C", "1n", C0603)
        s.connect("I_SENSE%d" % n, ("C_%s_F" % p, "1"))
        s.connect("AGND",          ("C_%s_F" % p, "2"))
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

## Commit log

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2026-08-13 feat: Frontplatte, Board-Mechanik, ESPHome-Konfiguration und Displayentscheid
    Erzeugt und verifiziert statt handgeschrieben - beide Generatoren pruefen ihr
    Ergebnis selbst.
    Frontplatte (mechanical/):
    - Parametrisches build123d-Modell einer Zentralplatte fuer 55er-Schalter-
    programme, Geraeteschrauben auf 60 mm nach DIN 49073
    - Export STEP + STL; STL ist wasserdicht und manifold (0 offene Kanten)
    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
    [bottom_power_motor.kicad_pcb, frontplate.step, frontplate.stl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]
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2026-08-13 feat: Sicheltasten und 1,43"-AMOLED - Frontplatte v2
    Antwort auf "Display zu klein": Die vier Tasten werden Ringsegmente um das
    Fenster statt Loecher daneben. Damit waechst das Fenster von Ø32 auf Ø37,4 mm
    (+26% aktive Flaeche, 3,8x Pixel), und die Tastflaeche je Taste verdreifacht
    sich. Geometrische Obergrenze mit Sicheltasten: ~Ø40 mm Fenster.
    Displayentscheid revidiert (docs/09, Revision 2):
    - Groessere runde LCDs (ST77916, ST77903) haben keinen ESPHome-Treiber -
    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
    [frontplate.step, frontplate.stl, frontplate_assembly.stl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]
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2026-08-13 docs: rechteckiges Display geometrisch geprueft - und zwei eigene Fehler korrigiert
    Neuer Abschnitt 1c in docs/09 beantwortet "warum kein Rechteck?" mit
    Geometrie statt Formensprache:
    - In einem runden Bauraum ist der Kreis flaechenoptimal. Das bestflaechige
    einbeschriebene Rechteck (Quadrat) erreicht nur 2/pi = 63,7 % der
    Kreisflaeche; 4:3 kommt auf 61 %, 16:9 auf 54 %.
    - Huellkreis auf dem Ø52-Board: Ø46 mm bei 3 mm Randabstand.
    Zwei Korrekturen an frueheren Aussagen von mir:
    1. Das 2,0"-Rechteck habe "fast die doppelte Flaeche" - falsch. Es sind
    +52 % gegenueber GC9A01 und nur +15 % gegenueber ST77916.
    2. Es sei eine Geschmacksfrage - falsch. Modul-Diagonale 54,0 mm gegen
    52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
2026-08-13 feat: ST77916 entschieden - laeuft ohne C++, Frontplatte darauf angepasst
    Displayentscheidung final: ST77916, 1,46" rund, 360x360, aktiv Ø37,25.
    Der befuerchtete Treiberaufwand entfaellt komplett: ESPHomes mipi_spi kennt
    ein "model: CUSTOM" mit "init_sequence" in YAML. Der ST77916 laeuft damit
    ohne jede External Component. Die Hersteller-Initialisierungssequenz aus
    espressif/esp-iot-solution (esp_lcd_st77916, Apache-2.0) liegt als
    st77916_init.yaml bei - 214 Kommandos, 11 Delays. INVON, SLPOUT und COLMOD
    bewusst ausgelassen, die setzt mipi_spi selbst.
    "esphome config" -> Configuration is valid.
    Folgefehler mitgefunden und korrigiert: Der ST77916 ist ein LCD und braucht
    eine Hintergrundbel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
    [frontplate.step, frontplate.stl, frontplate_assembly.stl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]
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2026-08-14 docs: Motorannahme korrigiert - keine Motorelektronik, H-Bruecke zwingend
    Nutzerangabe: der Motor hat KEINE eingebaute Hinderniserkennung (das macht
    der externe Controller, den dieses Projekt ersetzt) und zwei Adern.
    Damit ist mein Schluss aus der Datenblattzeile "Art des Endschalters:
    dynamisch" widerlegt. Ich hatte daraus interne Elektronik abgeleitet und
    zwei angenehme Folgerungen gezogen - beide falsch:
    - "PWM vermutlich verboten" -> PWM ist erlaubt, nichts stoert sich daran
    - "interne Strombegrenzung
    deckelt den Blockierstrom" -> nichts begrenzt ihn. I = U/R_Anker,
    Groessenordnung 8-30 A
    Zurueckgeholt werden damit: Stall-Erkennung als Ke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
2026-08-14 feat: Mid- und Top-Schaltplan, Stack-Pinout v0.3 als gemeinsame Quelle
    Mid (26 Bauteile, 52 Netze) und Top (24 Bauteile, 51 Netze), beide wie das
    Bottom-Board erzeugt und per kicad-cli-Netzliste rueckverglichen - BESTANDEN,
    offene Pins nur auf expliziter Freigabeliste (Strapping, PSRAM-Pins 35-37,
    SBU, Expander-INT).
    Mid: ESP32-S3-WROOM-1 mit vollstaendiger GPIO-Zuordnung (im Kopf des
    Generators dokumentiert), MAX3485 mit Fail-Safe-Bias und DNP-Terminierung,
    steckbarer RS485-Anschluss, PCF8574 auf 0x20 mit Portbelegung == YAML,
    Piezo-Treiber an 5V, EN-RC plus Reset- und Boot-Taster. Der KiCad-THVD1451D
    ist die Vollduplex-Variante ohne DE/RE, deshalb MAX3485.
    Top: USB-C (UFP, 5k1 an CC1/CC2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
    [bom_bottom.csv, bottom_power_motor.kicad_sch, mid_logic.kicad_sch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]
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2026-08-14 Routing-Pipeline auf Freerouting 1.9.0 + Xvfb umgestellt
    Zwei behobene Probleme:
    - Freerouting 2.1.0 headless exportiert die SES von einem aelteren
    Zwischenstand statt vom Endergebnis (6 Netze fehlten trotz gemeldeter
    0 offenen Verbindungen), ignoriert -mp und kann Float-Optionen per
    CLI nicht setzen. 1.9.0 unter xvfb-run routet klassisch, optimiert
    mit -oit-Abbruchschwelle und schreibt die SES vollstaendig.
    - SES-Import: pcbnew.ImportSpecctraSES braucht den Editor-Kontext und
    schlaegt standalone fehl; eigener Import (S-Expression-Parser, Wires
    und Vias inkl. Padstack-Masse) ersetzt ihn.
    Zusaetzlich wird die Board-Outline im DSN um 0,5 mm nach innen
    skaliert, damit der Router den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
    [route_boards.py]
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2026-08-14 Bottom: Leistungsklasse auf 0,8 mm / 0,2 mm entspannt
    Mit 1,0 mm Breite und 0,25 mm Clearance liess Freerouting nach 200
    Passes (62 min) noch 58 Verbindungen offen - zwischen den FET-Pads
    und um den Leistungsstecker passen die breiten Bahnen nicht ueberall.
    0,8 mm traegt bei 35 um Kupfer ~3 A dauerhaft (Laufstrom <= 1 A,
    Trip-Transienten kurz); Leistungspfade werden vor der Fertigung von
    Hand nachgezogen (docs/05).
    Claude-Session: https://claude.ai/code/session_017FTFDJW9R41k2WFeDRNE3w
    [route_boards.py]
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2026-08-14 Bottom: Standard-Vias und -Clearance fuer Leistungsklassen
    Die 0,8er-Vias mit 0,2er-Clearance passen nicht in die Schluchten
    zwischen den FET-Pads - die letzten ~50 Verbindungen blieben ueber
    mehrere Stunden Autorouting dauerhaft offen. Jetzt 0,6/0,3-Vias und
    0,15er-Clearance auch fuer PWR/RAIL auf dem Bottom-Board (2-3 A je
    Via, ausreichend fuer Laufstrom und kurze Transienten; Handnacharbeit
    der Leistungspfade vor Fertigung bleibt Pflicht per docs/05).
    Bottom-Fortsetzungslauf mit den entspannten Regeln laeuft. Zudem
    Bottom-Stand nach erster Fortsetzung (62 -> 53 offen) und Mid-Stand
    nach finalem Wandnetz-Lauf (J3-25/33-Kette per Stich angebunden,
    7 Paare offen, Iterator laeuft) uebernommen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
    [bottom_power_motor.kicad_pcb, mid_logic.kicad_pcb]
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2026-08-14 Bottom: Fortsetzungsstand uebernommen (51 offen), frischer Lauf gestartet
    Die Fortsetzung mit entspannten Regeln stagniert (53 -> 51 offen in
    einer Stunde) - die unter den strikten Regeln entstandene Verdrahtung
    verstopft die Korridore. Analog zum Mid-Board laeuft jetzt ein
    frischer Komplettlauf mit den entspannten Klassen (0,8 mm-Bahnen,
    0,6er-Vias, 0,15er-Clearance).
    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
    [bottom_power_motor.kicad_pcb]
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2026-08-14 Bottom: bester Routing-Stand uebernommen (43 offen, 0 Kupferfehler)
    Fortsetzungslauf auf der frischen Basis: 985 Segmente, 102 Vias,
    43 offene Signalverbindungen im Motor-/Leistungsteil (vorher 47),
    18 PGND/AGND-Pour-Anbindungen. Zonen wie beim Mid auf Vollanbindung
    und 0,15er-Clearance umgestellt; keine harten DRC-Fehler mehr.
    docs/05 mit den finalen Zahlen.
    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
    [bottom_power_motor.kicad_pcb]
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2026-08-15 Fertigungsnutzen: drei Platinen in einer Boarddatei
    KiCad kennt nur ein Board je Projekt - das Handbuch zu 10.0 sagt es
    woertlich. Statt die drei Quellen zu verschmelzen (und dabei alle
    Referenzbezeichner und die Moeglichkeit zu verlieren, ein Board allein zu
    revidieren) erzeugt tools/gen_panel.py den Nutzen aus ihnen. Er ist ein
    Build-Ergebnis wie die Gerber.
    Aufbau
    ------
    178,4 x 64,4 mm, drei Kreise Ø52 in einer Reihe, Teilung 57 mm, Fraesfuge
    2,2 mm, Rahmen 4 mm. Je Platine vier Stege von 4 mm auf den DIAGONALEN -
    alle vier Achsrichtungen sind belegt: 0/180 Grad die Befestigungsbohrungen,
    90 Grad der ueberstehende USB-C-Stecker auf Top, 270 Grad der
    Antennen-Keepout auf Mid. Fuenf Maus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
    [switchstack_panel.kicad_pcb]
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2026-08-15 USB-C-Buchse steht um 180 Grad verdreht - Drehung im Generator korrigiert
    Nachgemessen im Top-Layout, weil die Buchse im 3D-Bild falsch herum aussah.
    Sie ist es.
    Der Befund
    ----------
    Im Footprint USB_C_Receptacle_GCT_USB4085 liegen die THT-Pins am Ende y = 0,
    die Steckoeffnung am Ende y = +8,61 (auf F.Fab als Schlitz bei y = 6,1
    markiert). gen_layouts.py drehte J1 um 180 Grad. Damit zeigt die Oeffnung zur
    Platinenmitte und die Loetseite steht ueber den Rand - genau umgekehrt zur
    Absicht, die im Kommentar derselben Zeile steht ("Steckgesicht ueberhaengt").
    Das ist nicht kosmetisch. Sechs Bohrungen schneiden die Oe-52-Kontur an:
    SH bei (-4,32 / 24,64) r = 25,02 -> 0,22 mm ueber der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
    [gen_layouts.py]
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2026-08-15 Abdeckrahmen festgelegt: Busch-Jaeger 1721-914 (balance SI, 1-fach)
    Bestellnummer 2CKA001725A1555. Damit sind zwei bisher angenommene Masse
    bestaetigt und ein Risiko benannt.
    Bestaetigt
    Fenster 55 x 55 mm -> Platte 54,6 passt mit 0,2 mm Luft je Seite
    Aussen 81 x 81 mm -> die 76 mm breiten Ohren verschwinden dahinter
    Tiefe 12 mm -> sitzt vor der Wand, kein Anteil am 61-mm-Budget
    Bohrung 71 mm -> deckt die Oe-60-Dose sicher ab
    Offen
    -----
    Der Rahmen haelt durch Klemmung, und die Herstellerangaben sagen nicht, woran.
    Bei den SI-Serien greifen die Rastnasen ueblicherweise am Tragring - diese
    Frontplatte ersetzt den Tragring aber durch zwei angefo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
    [frontplate.step, frontplate_caps.step]
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2026-08-15 Stehende USB-C-Buchse, Nutzen mit gemischter Geometrie - Top ist DRC-sauber
    USB-C (Punkt 45)
    ----------------
    Gewaehlt: G-Switch GT-USB-7051x, vertikal SMT, 22 Pads (A- und B-Reihe
    vollstaendig, also steckrichtungsunabhaengig), Footprint 9,94 x 6,40 mm,
    LCSC C2843970. Sie sitzt mittig oben, zeigt nach vorn und liegt unter der
    Zentralscheibe - erreichbar erst nach deren Abnahme, so wie es Punkt 45
    verlangt.
    Der Nebeneffekt ist der eigentliche Gewinn: Die 28 clearance-Meldungen, die das
    Top-Board seit dem ersten Layout begleitet haben, sind verschwunden. Sie waren
    nie ein Layoutfehler, sondern die zu eng gerasterten Pads der liegenden GCT
    USB4085 gegen unsere 0,15-mm-Vorgabe. Das Top-Board me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
    [bom_top.csv, switchstack_panel.kicad_pcb, top_ui.kicad_pcb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]
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2026-08-17 M6: Nullpunkt der Messleitungen ergaenzt
    Erwartet werden rund 1 Ohm (24 V / 25 A). Messleitungen und Messgeraet bringen
    selbst 0,2 bis 0,5 Ohm mit - bis zur Haelfte des Messwerts. Ohne Abgleich misst
    man den doppelten Widerstand, errechnet den halben Blockierstrom und legt die
    Sicherung zu klein aus. Das Protokoll sagt das jetzt.
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2026-08-17 M7-Messung: 0,116 A bei 2 V ist der Leerlaufstrom, nicht der Blockierstrom
    Der Fehler liegt in meiner Anleitung, nicht in der Messung. In docs/11 stand,
    der Motor stehe bei 2 V, weil er die Haftreibung des Schneckengetriebes nicht
    ueberwinde. Er steht nicht - er dreht, nur unsichtbar: 1,9 U/min mal 2/24 sind
    0,16 U/min, also eine Umdrehung in gut sechs Minuten. Sobald er dreht, baut er
    Gegenspannung auf und der Strom bricht auf den Leerlaufwert zusammen.
    Die Gegenprobe zeigt es sofort: 0,116 A bei 2 V ergaeben R = 17,2 Ohm und
    1,4 A Blockierstrom. Das Typenschild nennt 100 W bei 24 V, also 4,17 A
    NENNstrom - ein Motor, der blockiert 1,4 A zieht, kann im Betrieb keine 4,17 A
    ziehen.
    Korrigi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
    [switchstack.yaml]
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2026-08-17 Kupferflaechen auf Mid und Top waren nie gefuellt - 76 offene Verbindungen weg
    Bei der Suche nach der Ursache der unvollstaendigen Boards zeigte sich, dass
    die PGND-Flaechen auf Mid und Top zwar korrekt angelegt und dem Netz zugeordnet
    sind, aber keinen einzigen filled_polygon-Block enthielten. Nur Bottom war
    gefuellt. Der Grossteil der gemeldeten offenen Verbindungen war deshalb gar
    kein Routing-Problem, sondern eine nicht ausgefuehrte Fuellung.
    vorher nachher
    bottom_power 61 61 (war bereits gefuellt)
    mid_logic 77 53
    top_ui 71 23
    Von 209 offenen Verbindungen sind 133 uebrig. Was bleibt, teilt sich in zwei
    verschiedene Auf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
    [bottom_power_motor.kicad_pcb, mid_logic.kicad_pcb, top_ui.kicad_pcb]
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2026-08-17 Die Zonenfuellung fehlte in der ganzen Pipeline - Ursache gefunden und behoben
    Warum die Boards unvollstaendig aussahen, war kein Routing-Problem.
    In gen_layouts.py stand seit langem der Kommentar, ZONE_FILLER.Fill() stuerze
    in der headless pcbnew-API ab - ein reproduzierbarer Segfault unter 7.0.11.
    Die Zonen blieben deshalb absichtlich leer, mit der Annahme, KiCad fuelle sie
    beim Oeffnen mit "B". Das ist nie passiert: Mid und Top hatten am 17.08.2026
    NULL filled_polygon-Bloecke.
    Unter KiCad 10 laeuft der Filler headless durch. Nachgeholt ergibt das:
    bottom_power 61 61 (war als einziges gefuellt)
    top_ui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
    [gen_layouts.py, route_boards.py]
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2026-08-17 Regelwerk und Router in Deckung gebracht: 41 Clearance-Fehler auf 5
    Drei getrennte Ursachen, alle aus derselben Wurzel - die Regeln, nach denen
    geroutet wurde, waren nicht die, nach denen geprueft wurde.
    1) DIE PROJEKTDATEIEN FORDERTEN 0,2 mm. docs/05 nennt 0,15 mm als gueltige
    Regel und warnt sogar ausdruecklich davor, dass KiCad ohne .kicad_pro auf
    0,2 mm zurueckfaellt und dann Verletzungen meldet, die keine sind. Genau
    dieser Wert stand aber IN den Projektdateien. Auf 0,15 korrigiert, in allen
    drei Projekten.
    Bottom clearance 41 -> 5
    Mid clearance 1 -> 0
    2) DER RANDKEEPOUT GALT NUR FUER F UND B. _edge_ring() hatte die Lagenliste
    fest verdrahtet; auf In1/In2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
    [bottom_power_motor.kicad_pcb]
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2026-08-18 Der Original-Controller bestaetigt die Strommessung ein viertes Mal
    Der mitgelieferte K0000230 lag offen auf dem Tisch. Drei Bauteile darauf
    sagen dasselbe wie unsere drei Messungen - und man muss dafuer nichts messen:
    Shunt 50 mOhm je Kanal bei 1,7 A sind das 85 mV und 0,14 W.
    Bei 20 A waeren es 20 WATT in einem Chipwiderstand.
    2x Infineon BTM7700G integrierte H-Bruecke, rund 110 mOhm im Strompfad.
    Bei 1,7 A 0,32 W, bei 20 A 44 W in einem SO-28.
    Elko 47 uF fuer zwei Motoren. Wer 20-A-Impulse abfaengt,
    baut Hunderte von Mikrofarad ein.
    Drei unabhaengige Bauteilentscheidungen, alle nur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
    [bottom_power_motor-bom-jlcpcb.csv, bottom_power_motor.kicad_pcb, bottom_power_motor.step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]
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2026-08-18 Stapelansicht als Bild, und das Feldstecker-Modell sass spiegelverkehrt
    docs/renders/stack.png zeigt die drei Boards in ihrer Stapelreihenfolge, aus
    den echten Boarddateien gerendert und uebereinandergelegt. Erkennbar sind die
    vier Ecktaster und die mittige Klinke auf Top, die Randkerbe an dessen linkem
    Rand, die quergestellte USB-Buchse auf Mid, die genau dorthin zeigt, und der
    lange Feldstecker auf Bottom.
    Erzeugt wird es aus drei Einzelrenderings mit transparentem Hintergrund, die
    mit 210 px Versatz uebereinandergelegt werden - eine Explosionsdarstellung
    ohne eigenes Rendersystem.
    MODELLFEHLER GEFUNDEN UND BEHOBEN: Die selbst erzeugten Steckverbindermodelle
    sassen spiegelverkehrt. Das F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
    [bottom_power_motor.kicad_pcb]
2026-08-18 docs/17: woher die Daten der vier offenen Bauteile kommen
    Display, Klinkenbuchse, USB-C und Feldstecker blockieren die Bestellung -
    jedes aus einem anderen Grund. Die Seite sagt je Teil, was genau fehlt, wo es
    herkommt und was davon abhaengt.
    DISPLAY ist der kritische Fall: Im Schaltplan steht ein Platzhalter, ein
    1,27-mm-Stiftleisten-Footprint mit zehn Pins und dem Vermerk PLATZHALTER. Es
    ist weder ein Bauteil gewaehlt noch ein Anschluss festgelegt.
    Dabei faellt eine Bauform schon raus: Die verbreiteten Fertigmodule mit
    Traegerplatine messen 48 x 31 mm - einen Millimeter breiter als unser
    Top-Board. Es muss ein nacktes Panel mit FPC-Fahne sein, rund 30 x 36 mm.
    Kandidaten bei buydisplay.c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
    [mid_logic.kicad_pcb, top_ui.kicad_pcb]
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2026-08-18 Display nach Datenblatt verdrahtet - und die Beleuchtung bekommt einen Treiber
    Das Datenblatt ER-TFT1.69-3 liegt vor, als Auszug gesichert in
    docs/datasheets/. Zwei Dinge daraus aendern den Schaltplan.
    DAS RASTER IST 0,50 mm, nicht 0,7 wie bei der Loetvariante. Das provisorisch
    gewaehlte Footprint TE 1-1734839-2 stimmt also.
    DIE PINBELEGUNG WAR KOMPLETT FALSCH. Sie stammte vom alten Platzhalter:
    war ist laut Datenblatt
    1 3V3 2 GND 1 TE 2 GND
    3 SCK 4 SDA 3 RS 4 RESET
    5 DC 6 frei 5 SDA 6 SCL
    7 frei 8 CS 7 CS 8 VCC
    9 RESET 10 BL 9 IOVCC 10 LEDA
    11 GND 12 GND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
    [top_ui.kicad_pcb, top_ui.kicad_sch]
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2026-08-19 Leistungsvias, Via-Strompruefung, Reset/Boot-Durchgriffe und der Gehaeusebecher
    VIER ARBEITEN AUS EINEM ABEND, alle aus Rueckfragen entstanden:
    1. VIAS SIND NICHT BELIEBIG STROMTRAGFAEHIG - der Einwand traf: 24V_IN
    lief ueber genau EIN 0,6/0,3-Via (~1,2 A) bei 4,1 A Grenzstrom, dazu 14
    weitere Engpaesse auf Bottom. Ursache: Die Bottom-Klassen routeten mit dem
    Standardvia - ein Erbe der diskreten H-Bruecke, zwischen deren FETs das
    0,8er nicht passte; Mid und Top hatten das Leistungsvia laengst. Jetzt:
    PWR- und RAIL-Klasse auf Bottom mit 0,8/0,4, Massebruecken dort ebenso
    (deren Platzsuche folgt jetzt der Viagroesse - die alte 0,6er-Suche setzte
    0,8er-Vias in 0,6er-Luecken, vier Abstandsfehle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
    [adapter.step, adapter.stl, bottom_power_motor.kicad_pcb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]
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2026-08-20 Bestellfaehigkeit Punkt fuer Punkt - und das Flip-Flop war unbestueckbar
    Die Frage "was ist entscheidend fuer Fertigung und Bestueckung?" wurde als
    Sieben-Punkte-Liste beantwortet und abgearbeitet:
    1. NETZE: Zweiter Freerouting-Pass ueber alle drei Boards - die neue
    Erkenntnis (Altbahnen gelten als Vorverdrahtung) als Werkzeug genutzt.
    Mid faellt auf 3 offene Signale. Top ist geometrisch festgefahren (9),
    Bottom nach Neuerzeugung bei seinen Restnetzen - alles dokumentierte
    Handarbeit in docs/16. gen_fab bleibt bis dahin zu Recht verriegelt.
    2. KUPFER: Alle drei Boards null Fehler. Drei Nacharbeiten auf dem Weg:
    ein Brueckenvia 0,33 mm vor der Bottom-Kante nach innen gerueckt, das
    RELAY_CTL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
    [bottom_power_motor-bom-jlcpcb.csv, bottom_power_motor.kicad_pcb, mid_logic-bom-jlcpcb.csv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]
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2026-08-20 Displayfahne wird direkt geloetet - Raster war 0,7, und beide Tore fallen
    Das Foto und die Originalzeichnung des Panels (vom Nutzer eingebracht)
    korrigierten die Datenlage grundlegend:
    * Raster 0,70 mm ("P0.7*(12-1)=7.7"), NICHT 0,50 - meine fruehere
    "0,50 bestaetigt"-Korrektur in docs/17 war der Fehler, die
    urspruengliche 0,7-Warnung war richtig. Die TE-Buchse passte nie.
    * Fahne nur 12,96 +-0,3 lang (nicht 18,15), Finger 0,35/2,0,
    Kontakte auf der VORDERSEITE der ungefalteten Fahne, 12 links /
    1 rechts.
    * Panelrueckseite SELBSTKLEBEND ("Remove Tape 0,15 max") - die
    Montage ist Werksklebeband, exakt unsere Klebefugen-Annahme.
    ENTSCHEIDUNG (Nutzer): DIREKTLOETEN.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
    [switchstack_panel-bom-jlcpcb.csv, switchstack_panel.kicad_pcb, top_ui-bom-jlcpcb.csv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]
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2026-08-20 Explosionszeichnung erzaehlt die Einbaureihenfolge - Feldstecker zuerst
    Schnitt A ist auf Wunsch in die echte Montagefolge umsortiert:
    Feldstecker (neu gezeichnet - er fehlte schlicht) -> Bottom -> Mid ->
    Tragring -> Abdeckrahmen -> Scheibenadapter -> Top-Board (mit Panel und
    Schaum) -> Zentralscheibe zuletzt, kraftfrei aufgeklickt. Der Untertitel
    sagt es jetzt woertlich: Reihenfolge = Einbaureihenfolge.
    Die eng zusammengerueckte Mittelgruppe brauchte vier Anlaeufe
    Beschriftungsstaffelung (Tragring/Adapter/Rahmen in drei Baendern,
    Texte gekuerzt, Schaumfahne hoeher) - per Bildausschnitt geprueft.
    [mid_logic.kicad_pcb, top_ui.kicad_pcb]
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2026-08-20 Der Rest-Schliesser findet seine Netze - drei Reparaturen und ein ehrliches Ende
    Die Kette pass3 + rest_schliessen lief scheinbar durch, hatte aber drei
    Loecher: GetBoardPolygonOutlines braucht in KiCad 10 ein zweites
    Argument (beide Runden crashten sofort), Outline(0) liefert eine
    SWIG-Referenz ins freigegebene Poly-Set (Segfault ohne Traceback, per
    faulthandler gefunden), und KiCad 10 schreibt den Netznamen nicht als
    Feld ins DRC-JSON, sondern nur in den Beschreibungstext - beide
    Werkzeuge lasen also fuer jede offene Verbindung ein leeres Netz.
    Dazu ein neuer Fall: deckungsgleiche Pads auf F und B bekommen ein
    Via mittenhinein.
    Freerouting hatte im pass3 ausserdem RELAY_CTL wieder 15 um z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
    [bottom_power_motor.kicad_pcb, mid_logic.kicad_pcb, top_ui.kicad_pcb]
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2026-08-20 Wie loetet man die Fahne? Das Buegel-Rezept steht jetzt in der Doku
    Frage des Nutzers: von oben den heissen Kolben auf die Fahne? Ja -
    Hotbar von Hand, durch die 0,13er Folie. Die drei Bedingungen stehen
    jetzt bei den Displaydaten: Lot VORHER duenn auf die Pads (verzinnen
    und mit Litze abziehen, wegen der 0,15er Fuge), Fahne im aufgeklappten
    Buch fixieren (Werksfaltung als Scharnier - so liegen die Finger von
    allein face-down), dann Pin fuer Pin ruhig durchbuegeln mit Kontrolle
    am Padstummel. Zug- und Durchgangsprobe vor dem Zuklappen.
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2026-08-21 Die y-Falle: drei Ausschnitte lagen spiegelverkehrt
    Der Nutzer hat es mit blossem Auge gesehen - 'warum hat der Tragring
    oben eine Aussparung?'. Die Antwort: weil KiCad y NACH UNTEN zaehlt und
    build123d nach oben, und die gedruckten Teile die Layout-Zahlen direkt
    uebernommen hatten. Betroffen waren alle drei Ausschnitte, die aus dem
    Layout kommen: USB-Freistellung im Adapter, Kabeldurchlass im Tragring,
    Steckertunnel im Becher. Der Tunnel stand zusaetzlich auf einer
    veralteten Position (-10,5 / 15,6 statt J1 bei 0,0 / 17,5).
    Beweis statt Vermutung: Am exportierten top_ui.step nachgemessen - die
    USB-Randkerbe steht im Layout bei y = +8 und im STEP bei y = -8.
    Behoben, ohne die Vergleichbark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
    [adapter.step, adapter.stl, gehaeuse.step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]
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2026-08-21 Stapelverbinder entschieden: 6,0 mm Ebenen, C41370657 + C43383
    Die zweite Recherche hat einen Rechenfehler von mir korrigiert, der die
    ganze Massekette bestimmt: Die 2,4 mm der Buchse C41370657 sind ihr
    LOETPIN, nicht die Einstecktiefe. Beim Stecken stossen die
    Kunststoffkoerper aneinander, es gilt also
    Spalt = Isolatorhoehe des Stifts + Buchsenhoehe
    Eingriff = Pin-Ueberstand - (Spalt - Buchsenhoehe)
    Damit braucht der guenstigste Stift 5,80 mm - bei den gestern gesetzten
    5,0 mm haette JEDER am Markt verfuegbare Stift geklemmt. 6,0 ist die
    naechste Standard-Huelsenlaenge und laesst 1,35 mm Kontakteingriff.
    Ausserdem bestaetigt: Einen beidseitig 3,1 mm ueberstehenden Stift gibt
    es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
    [gehaeuse.step, gehaeuse.stl, mid_logic.kicad_pcb]
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2026-09-15 Punkt 23 im Layout: Mid traegt den Durchsteck-Stift, mit dem Lochbild der Buchse
    Seit dem Beschluss (C43383 auf Mid, C41370657 auf Bottom und Top) sass im
    Layout auf allen drei Boards noch die Buchse. Der naheliegende Tausch auf
    KiCads PinHeader_2x20_P1.27mm_Vertical geht nicht: Der Header hat Reihe 2
    bei +1,27, die Buchse bei -1,27. Ein Tausch haette 40 Bohrungen um 2,54 mm
    verschoben und jede Bahn dorthin abgerissen - und gesteckt haette es auch
    nicht mehr, weil die Stifte in die Buchsen der Nachbarn muessen, also auf
    DEREN Lochbild.
    Deshalb ein projektlokaler Footprint SwitchStack:PinHeader_2x20_P1.27mm_
    Vertical_Durchsteck: Pads und Bohrung (0,7) wie die Buchse, Beschreibung
    sagt warum,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
    [mid_logic.kicad_pcb, mid_logic.kicad_sch]
